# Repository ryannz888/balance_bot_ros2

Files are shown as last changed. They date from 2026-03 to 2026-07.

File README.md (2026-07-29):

# balance_bot_ros2

Two-wheeled self-balancing robot. Raspberry Pi 5 + Arduino Mega + IMU + depth camera, ROS 2 Jazzy.

Stands on its own indefinitely, drives under gamepad or keyboard control while balancing,
stops itself when the depth camera sees something in the way, and will drive around
a room on its own, turning away from whatever it finds.

| | measured |
| --- | --- |
| Continuous balance | **361 s** in one unbroken segment, still upright when recording stopped |
| Driving | **755 s** of gamepad driving with zero falls |
| Pitch error, station keeping | **0.34 deg RMS**, inside ±1.3 deg |
| Braking distance | **0.10 m** from 0.174 m/s |
| Obstacle scan | 1.98 m baseline with 0.01 m scatter; detects at 0.53–0.71 m |
| Autonomous | **486.9 s** of unbroken balance while driving, turning and reversing on its own |

## What was actually hard

A balancing robot is open-loop unstable and **non-minimum phase**: to slow a forward roll the
wheels must first drive *forward*, so the base moves ahead of the centre of mass and the body
pitches back. Get that backwards and the outer loop becomes positive feedback.

That is exactly what happened. `kp_v` was positive for three days and the robot could not hold
more than 8 seconds. The fix came from deriving the sign twice — once from the physical
transient, once from the characteristic equation `s² − K'·kp_v·s − K'·ki_v = 0`, which requires
both gains negative for stability. Setting `kp_v = −0.005` took the longest run from **7.8 s to
367 s in a single step**.

The rest of the tuning was data-driven rather than trial and error:

- **Damping vs stiffness.** A slow 0.45 Hz surge looked like too little damping. Estimating
  ζ ≈ 1.31 from the observed period showed the loop was already overdamped, so the answer was
  more position stiffness, not more damping.
- **The balance point was measured, not guessed.** While balancing with zero mean wheel speed,
  the mean pitch *is* the mechanical balance point: 7.53°. Judged by the velocity integral
  collapsing from −322 to −49 and no longer clamping.
- **Judder was identified as loop self-excitation, not mechanical resonance** — the oscillation
  frequency moved from 9.18 Hz to 7.07 Hz when a software filter coefficient changed, which a
  structural resonance cannot do. Lowering `kd` removed it at no cost to station keeping.
- **A regression was traced to a loose fastener, not to parameters.** Several unrelated metrics
  degraded at once and reverting the parameter did not restore them. That pattern is now a
  documented rule: stop tuning, inspect hardware.

Perception and autonomy produced the same kind of findings. The robot stopped far from
obstacles not because thresholds were timid but because the corridor was a wedge, which
flares to eight times the robot's width at 3 m. It drove into a table leg it had tracked
the whole way in, because the guard's speed taper and the explorer's turn threshold
overlapped into a dead zone where neither reacted, at a commanded speed the drivetrain
cannot even produce. And it engaged while not balanced because a frozen IMU reading
presents as constant error with zero rate -- which is exactly the condition for engaging.

Full reasoning, including the negative results and the conclusions that were later
overturned, is in [`docs/`](docs/).

## Architecture

```text
HFI-A9 IMU ──USB──► hfi_imu_node ──► /imu/data (~145 Hz)
                                         │
                                    level_frame_publisher ──► base_link_level (gravity-aligned)
                                         │
Astra depth ──► openni2 ──► /depth/image ──► obstacle_scan ──► /obstacle/scan (LaserScan, 30 Hz)
                                                                    │
explorer ──/cmd_vel_auto───┐                                        ▼
                           ├─ cmd_mux ─► /cmd_vel_raw ─► avoidance_guard ─► /cmd_vel ─► balance_controller
teleop ──/cmd_vel_manual───┘  (manual wins)   (limits forward only)     │
                                                                /motor_cmd (PWM/100)
                                                                       ▼
                                    serial_bridge ──"M,<pwm>,<pwm>"──► Arduino ──► motors
                                          ▲                               │
                                          └───"E,<left>,<right>" 100 Hz───┘
```

Each boundary in that chain exists for a reason found by breaking it:

- **`/cmd_vel` vs `/motor_cmd`.** Both teleop and the controller once wrote `/cmd_vel` and
  overwrote each other, so driving while balancing was impossible. `/cmd_vel` is now human
  intent in SI units; `/motor_cmd` is the PWM setpoint.
- **`/cmd_vel_raw` vs `/cmd_vel`.** The guard owns `/cmd_vel`; command sources publish
  `/cmd_vel_raw`. The topic name *is* the enforcement — a source that writes `/cmd_vel`
  directly bypasses the guard.
- **`base_link_level`.** The TF tree roots at `base_link`, so everything downstream implicitly
  treats the body as level. It never is. At 1 m, four degrees of tilt is 7 cm of apparent
  height — the whole difference between floor and obstacle.
- **The corridor is a strip, not a wedge.** It was a fixed half-angle, which flares with
  distance: ±0.30 rad spans 1.86 m at 3 m against a 0.22 m track, so distant objects well
  off to the side read as blocking. That, not conservative thresholds, was why the robot
  stopped while still far from anything.

Driving needed **no new control loop**. The velocity and yaw loops already regulate wheel speed
and left/right difference to zero; teleop only moves those setpoints off zero.

## Failing safe

Losing the link on a balancing robot means falling over, not stopping. Every stage fails closed:

| | |
| --- | --- |
| Command timeout | setpoint ramps to zero, robot keeps balancing in place |
| Setpoint slew limit | a step command would demand an instant lean the body cannot produce |
| Input clamp | `teleop_twist_keyboard` defaults to 0.5 m/s, past what this machine can hold |
| Deadman button | releasing stops the robot |
| No attitude → no scan | `obstacle_scan` publishes nothing rather than a scan that reads clear |
| No scan → no forward | the guard reports `STALE` and allows 0% forward |
| Frozen IMU → disengage | 40 bit-identical pitch samples means a dead source, not a still robot |
| Serial device lost | both serial nodes reopen through the by-id path rather than spinning on a dead handle |
| Unknown ≠ clear | invalid depth pixels are absence of evidence, published as `NaN`, never as free space |

That last one is the one that matters most and the one most easily got wrong — see
[`docs/08`](docs/08_MVP2深度相机接入_2026-07-28.md) for how it was got wrong here first.

## Running it

Installed as a systemd unit, the robot comes up on its own: power it on, set it
upright, and it explores. Holding the gamepad's deadman button takes control;
releasing it returns to exploring half a second later.

```bash
sudo systemctl enable --now balance-bot     # boot into autonomy
journalctl -u balance-bot -f                # live
ls -t ~/robot_logs/                         # per-boot logs and bags
```

By hand, in this order:

```bash
ros2 launch balance_bot balance.launch.py     # stands and drives
./run_camera.sh                               # depth driver
ros2 launch balance_bot autonomy.launch.py    # perception, guard, autonomy, gamepad
ros2 launch balance_bot autonomy.launch.py explore:=false   # manual, still guarded
```

Set the robot upright and let go; it engages itself. Analysis of a recorded run:

```bash
scp -r pi:~/ros2_ws/bags/run1_<stamp> results/rosbag/
python tools/analyze_teleop.py results/rosbag/run1_<stamp>
```

## Hardware

| Component | Role |
| --- | ---- |
| Two-wheeled base with encoders | 277.5 counts/rev, 65 mm wheels, 220 mm track |
| Arduino Mega 2560 | TB6612 motor driver, encoder ISR, serial protocol, command watchdog |
| Raspberry Pi 5 (Ubuntu 24.04, ROS 2 Jazzy) | control, perception, logging |
| HFI-A9 IMU | fused quaternion over USB serial, driver written from the protocol |
| Orbbec Astra depth camera | 640×480 depth at 24 Hz, discontinued — see below |

The Astra is discontinued and its official OpenNI2 repository is gone. The current Orbbec SDK
does not recognise it, and Debian's `libopenni2` ships only the PrimeSense driver. Depth works
here by taking the prebuilt `liborbbec.so` out of `orbbec/ros2_astra_camera`, installing it as
`liborbbec.so.0` because Debian's loader only scans for versioned names, and running the camera
node against Orbbec's own `libOpenNI2` — Debian's enumerates the device but segfaults on stream.

## Tooling

Everything under [`tools/`](tools/) exists because something needed measuring:

| | |
| --- | --- |
| `analyze_teleop.py` | scores a run from the bag, using the controller's own recorded state |
| `analyze_run.py` | replays the controller state machine offline, for bags without it |
| `teleop_sequence.py` | scripted command sequences, repeatable across runs |
| `check_level_frame.py` | verifies the gravity frame by rotating measured gravity through it |
| `depth_geometry.py` | checks a depth frame's 3-D geometry for self-consistency |
| `loadtest_camera.sh` | measures whether streaming depth costs the control loops anything |
| `joymap.py` | maps a gamepad's real axis and button indices in one pass |

Braking distance was never measured deliberately — it was computed from bags recorded days
earlier for tuning, because every teleop command is followed by a release.

## Status

- [x] Week 1–4: IMU driver, motor and encoder verification, serial bridge, URDF and TF
- [x] **MVP0** — keyboard teleop with encoder-driven live RViz
- [x] **MVP1** — balance PID (four-stage cascade), driving under balance, gamepad, recording and analysis
- [x] **MVP2** — depth perception, gravity-aligned obstacle scan, avoidance guard, autonomous wandering
- [ ] Odometry (encoders on a pitching body do not measure ground distance directly), then SLAM

Autonomy steers for gaps rather than stopping at obstacles: every bearing is tested for
whether the robot would fit through it, and the widest gap wide enough is steered toward
while still driving. A 0.4 m opening is taken, a 0.2 m one is refused.

Its limit is the sensor, not the logic. With a 58° horizontal field of view the robot
cannot see where it is about to turn until it has turned, so escaping an enclosed space
is search rather than planning. A wider sensor, or remembering what was seen a moment
ago, is the next real improvement.

Known open items are recorded with reproduction steps rather than omitted — the most
significant is that driving forward can lock up below the static-friction threshold, and why
one attempt to fix it made things worse. See [`docs/07`](docs/07_遥控与录制_2026-07-26.md) §11.

## Engineering notes

- Serial devices open via `/dev/serial/by-id/` — `ttyACM*` numbering drifts across boots
- The left/right harness (motors **and** encoders) was cross-wired at assembly; normalised in
  `serial_bridge` and verified wheel by wheel
- `/joint_states` is decimated to 20 Hz; 100 Hz TF saturates a hotspot link
- The camera driver stamps from its own clock by default, which drifted 17 s and silently broke
  attitude pairing — `use_device_time:=false`
- Depth is never streamed off-board: 640×480 float32 at 24 Hz is ~29 MB/s. The robot computes
  and publishes a 64-range scan instead

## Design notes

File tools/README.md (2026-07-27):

# 调参分析工具

2026-07-25 调参过程中使用的离线分析脚本。用法与结论见
`docs/06_PID调参完全复盘_中文.md`。

依赖：`pip install rosbags numpy`

工作流：

```bash
# 1. Pi 上录包（launch 自带，不用手敲话题清单）
ros2 launch balance_bot balance.launch.py record:=true bag_name:=myrun

# 2. 拉回本地
scp -r pi:~/ros2_ws/bags/myrun_<时间戳> results/rosbag/

# 3. 分析
cd tools
python analyze_teleop.py ../results/rosbag/myrun_<时间戳>      # 有 /balance/state 时首选
python analyze_run.py    ../results/rosbag/myrun_<时间戳> 7.53 3.0 12.0 600 5.0
```

**停录制要用 `SIGTERM` 不是 `SIGINT`**：非交互 shell 里的后台任务会继承
"忽略 SIGINT"，`kill -INT` 打不停 recorder，metadata.yaml 就不会写，
包直接读不了。

## analyze_teleop.py

2026-07-26 起的首选工具。直接读 `/balance/state`，不再离线重放状态机。

```
参数：<bag路径>
```

输出：接管分段、每条遥控指令的**设定值跟随情况**（v_ref→vel、turn_ref→turn，
同时给 ticks/s 和 m/s）、无指令时的站桩指标、以及全程位置漂移。
指令块只统计后半段的均值，避开斜坡未到位的部分。

## teleop_sequence.py

发一段脚本化的速度指令序列到 `/cmd_vel`，用于可复现的阶跃测试。

```
参数：[线速度 m/s] [角速度 rad/s]      默认 0.08 / 0.5
```

**不要用 shell 循环套 `ros2 topic pub` 代替它。** 每次 `ros2 topic pub` 都是新进程，
在 DDS 发现匹配上已有订阅者之前就开始发，VOLATILE 语义下这些消息对尚未被发现的
订阅者直接丢弃。第一次遥控测试就栽在这：包里录到了 34 条前进指令，
控制器的回调**一次都没触发**。本脚本全程只用一个 publisher，
并且在 `get_subscription_count() > 0` 之前不发任何消息。

## analyze_run.py

主力工具。离线复现控制器状态机，逐段输出指标。

```
参数：<bag路径> [offset] [engage_below] [max_tilt] [max_wheel_v] [最短报告时长]
```

输出两张表。第一张按段列出：时长、**退出原因**（`TILT` 倾角超限 / `WHEEL` 轮速超限 /
`END` 录制结束时仍在平衡）、误差范围、平均 PWM、饱和率、**带符号**平均轮速、
最大轮速、过零次数、平均差模轮速（偏航偏置）。

第二张是位置环诊断：位置峰峰值与标准差（单位：轮周）、摆动周期、
速度与误差的 RMS。摆动周期用 0.4 秒滑动平均后的轮速过零来数，
直接数原始轮速会数到噪声（会得到 6~9 Hz 的假结果）。

最后是各 PWM 区间的轮子移动率，用于粗看静摩擦。

## true_offset.py

从平衡数据反推真实机械平衡点，替代静态标定。

```
参数：<bag路径> <当前offset> <kp_v> <ki_v> [velocity_filter_alpha]
```

原理：车在平衡且长时间平均轮速为零时，平均 pitch 就是真实平衡点。
同时重建控制器内部的 `velocity_integral` 并报告其均值与限幅占比——
**零点精修到 0.2° 以下时应以积分均值为判据**（应接近 0 且不限幅），
平均 pitch 在这个尺度上已是 run-to-run 噪声。

## breakaway.py

测负载下的静摩擦突破电压，分正反方向。可同时传多个 bag 合并统计。

```
参数：<bag路径> [更多bag路径...]
```

**关键实现**：只统计"指令已稳定"的样本（与 100 ms 前相差 <15 PWM），
排除 PWM 正在爬升的瞬态。不加这个过滤会系统性低估阈值——
最初正是因此误判"静摩擦不是瓶颈"。

## jerk_trace.py

打印轮速极值时刻前后 2 秒的原始逐点轨迹（pitch / err / rate / pwm / vel / turn）。

```
参数：<bag路径> <offset>
```

聚合统计看不见的问题要靠它。stick-slip 极限环就是用它诊断出来的：
持续给 -45 PWM 而轮速恒为 0，车身自己前倾，PWM 追到 116 才挣脱，
随后暴冲到 341 ticks/s 并过冲到 -2.07°。

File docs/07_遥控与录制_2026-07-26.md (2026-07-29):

# 遥控控制与 rosbag 录制（MVP1 后半段）

> 2026-07-26。前置：`docs/06_PID调参完全复盘_中文.md`（平衡环整定，已完成）。
>
> 本篇记录在已经能站稳的平衡车上加遥控的全过程：架构怎么改、
> 为什么遥控不需要新回路、失效保护放在哪、以及一路踩下来的坑。

---

## 1. 起点与阻塞点

07-25 收工时车能连续平衡 228 秒，但整个系统只有一个 `/cmd_vel`，
而且它被两个语义完全不同的东西同时占用：

| 谁 | 用 `/cmd_vel` 表示什么 | 单位 |
| --- | --- | --- |
| MVP0 键盘遥控 | 人的速度意图 | m/s、rad/s |
| balance_controller | 给 serial_bridge 的 PWM 指令 | PWM/100 |

`serial_bridge` 订阅 `/cmd_vel` 直接转 PWM 下发。所以**只要平衡控制器在跑，
键盘遥控和它就会抢同一个话题互相覆盖** —— 这是加遥控前必须先解决的事，
不是风格问题。

---

## 2. 话题分层

```
teleop ──/cmd_vel(SI单位,意图)──► balance_controller ──/motor_cmd(PWM/100)──► serial_bridge
                                          │
                                          └──► /balance/state (诊断)
```

实现上没有硬改 `serial_bridge`，而是给 `bringup.launch.py` 加了一个
launch 参数，默认值保持 `/cmd_vel`：

```python
DeclareLaunchArgument('motor_cmd_topic', default_value='/cmd_vel'),
...
Node(package='balance_bot', executable='serial_bridge',
     remappings=[('/cmd_vel', LaunchConfiguration('motor_cmd_topic'))]),
```

`balance.launch.py` 里传 `/motor_cmd` 覆盖它。这样 **MVP0 的键盘直驱用法
一行都不用改**，裸 bringup 依然是 `/cmd_vel` 直通电机。

> 经验：给已有系统加抽象层时，把新语义放在**默认值之外**，
> 旧用法就不会被打断。

---

## 3. 核心洞察：遥控不需要新回路

这是本次最值得讲的一点。

平衡车的串级结构里，速度环和偏航环本来就在**调节两个物理量**：

- 速度环把平均轮速调节到 **0**
- 偏航环把左右轮速差调节到 **0**

"站着不动"只是"设定值为 0"的一个特例。所以遥控要做的不是新增控制器，
而是**把这两个 0 换成指令值**：

```python
vel_err  = self.wheel_velocity - self.v_ref      # 原来隐含 v_ref = 0
turn_err = self.turn_velocity  - self.turn_ref   # 原来隐含 turn_ref = 0

offset_trim     = kp_v * vel_err + ki_v * self.velocity_integral
sync_correction = wheel_sync_kp * turn_err
```

改动就是两行里各加一个减号项。已经整定好的增益**完全不用重调**，
因为回路的动力学没变，只是工作点移了。

---

## 4. 单位换算（从已有标定量推，不重新测）

| 量 | 来源 | 值 |
| --- | --- | --- |
| 编码器分辨率 | `serial_bridge` 的 `ticks_per_rev` | 277.5 计数/圈 |
| 轮半径 | URDF `cylinder radius` | 0.0325 m |
| 轮距 | URDF 左右轮 joint origin ±0.11 | 0.22 m |

```
周长 = 2π × 0.0325 = 0.2042 m
ticks_per_meter = 277.5 / 0.2042 = 1358.9        → 1 m/s = 1359 ticks/s
```

节点启动时会把这个数打出来自检，实测日志 `1358.9 ticks/m`，与手算一致。

**由此得到一个重要约束**：安全限 `max_wheel_velocity = 600 ticks/s`
换算过来只有 **0.44 m/s**。而 `teleop_twist_keyboard` 默认速度是 0.5 m/s，
直接超限。所以指令**必须在控制器内部钳位**，不能信任输入源。

偏航换算（差速驱动）：

```
v_left = v - ω·L/2 ,  v_right = v + ω·L/2
turn   = v_left - v_right = -ω·L
turn_ref[ticks/s] = -ω · 0.22 · 1358.9 = -299 · ω    → 1 rad/s = 299 ticks/s 差模
```

负号来自 REP-103：`angular.z` 为正是**左转（逆时针）**，左转时右轮更快，
所以差模设定值取负。台架实测 +0.5 rad/s 得到 `turn_ref = -149.5`，
与 `-0.5 × 0.22 × 1358.9 = -149.5` 完全吻合。

---

## 5. 失效保护三件套

平衡车上遥控失效不是"停下来"，是"摔倒"，所以这部分比功能本身重要。

**① 指令超时回零**（`cmd_timeout_s: 0.5`）
断连、teleop 进程崩溃、手柄没电、Wi-Fi 抖动 —— 任何一种都会让
`/cmd_vel` 停发。此时设定值斜坡回零，**车原地继续平衡**，
而不是保持最后的速度冲出去。

> 这条决定了失效保护必须做在**控制器里**，而不是指望输入端。
> 手柄的死人开关是第二道防线，不是第一道。

**② 设定值斜坡限速**（`cmd_accel_ticks_s2`）
阶跃指令要求车身瞬间改变倾角，非最小相位系统做不到。见第 8 节实测。

**③ 幅值钳位**（`max_cmd_linear_mps: 0.25`、`max_cmd_angular_rps: 1.2`）
无论上游发什么，进环的设定值都在物理可承受范围内。

另外**未接管时输出硬零**：实测在车躺在地上、持续发
`{linear.x: 0.2, angular.z: 0.5}` 的情况下，`/motor_cmd` 全零。

---

## 6. `/balance/state` 诊断话题

改造前，离线分析必须**重放控制器状态机**才能还原哪些时段在平衡
（`analyze_run.py` 的做法）。现在控制器直接把自己的内部视角发出来：

```python
STATE_FIELDS = ('pitch','err','rate','trim','offset','vel','vel_raw','turn',
                'v_ref','turn_ref','vel_int','u','sync','engaged')
```

用 `Float32MultiArray`，字段名写进 `layout.dim[0].label`，
**包本身是自解释的**，不依赖源码版本。48 Hz（IMU 帧率 3 分频）。

这一步的收益在第 8 节体现得很直接：后退超调的机理，是靠逐点打印
`v_ref / vel / trim / err / u` 一眼看出来的 —— 靠聚合统计看不见。

---

## 7. rosbag 录制集成

```bash
ros2 launch balance_bot balance.launch.py record:=true bag_name:=teleopT5
```

launch 里用 `ExecuteProcess` + `IfCondition` 挂 recorder，自动附加时间戳、
mcap 格式、固定 6 话题（`/imu/data /wheel/encoders /joint_states
/cmd_vel /motor_cmd /balance/state`）。省掉每次手敲话题清单，
也保证每个包的话题集一致、可比较。

---

## 8. 遥控整定实录

测试用 `tools/teleop_sequence.py`：前进 / 后退 / 左转 / 右转，
各 3 秒，间隔 6 秒（间隔同时在验证指令超时）。

### T1 — 测出来的是测试脚本的 bug

分析报告只有两个偏航指令块，两个直线指令块**完全没有**。
但包里明明录到了 34 条 `linear.x=0.08`。

进一步查：`v_ref` 全程精确为 `0.000000`，控制器日志里"遥控指令接入"
只出现 **2 次**（应该 4 次）。

**根因**：测试脚本用 shell 循环套 `ros2 topic pub`，每条指令一个新进程。
`ros2 topic pub` 在 DDS 发现匹配上已有订阅者**之前**就开始发，
VOLATILE 语义下这些消息对尚未被发现的订阅者直接丢弃。
录包节点被发现了，控制器没有 —— 于是包里有数据，回调一次没触发。

**修复**：改成常驻单 publisher，且在 `get_subscription_count() > 0`
之前不发任何消息（`tools/teleop_sequence.py`）。

> 教训：**"发出去了"和"收到了"是两回事**。rosbag 记录的是录包节点
> 收到的，不等于目标节点收到的。验证链路要看接收端的证据。

### T2 — 台架验证（车躺地上，未接管）

把设定值斜坡改成与接管状态无关后，可以在车不动的情况下验证整条指令链路：

| 指令 | 期望 | 实测 |
| --- | --- | --- |
| 前进 0.08 m/s | +108.7 ticks/s | **+108.7** |
| 后退 0.08 m/s | −108.7 | **−108.7** |
| 偏航 ±0.5 rad/s | ±149.5 | **±149.5** |
| 斜坡 250 ticks/s² | 0.43 s 到位 | ~0.4 s |
| 超时回零 | 0.5 s 后衰减 | ✓ |

`engaged` 全程 0，电机硬零。**能在不冒摔车风险的情况下验证的东西，
就不要在车上验证。**

### T3 — 第一次真正行驶

4 条指令全部生效。但出现两个问题。

**问题 A：跑飞保护误触发 3 次**

```
raw=-639.1  filtered=-306.8
raw=-620.6  filtered= -71.7    ← 滤波后几乎静止
raw=+818.3  filtered= +51.6    ← 滤波后几乎静止
```

原判据用的是**未滤波**轮速。而 277.5 计数/圈、10 ms 窗口下，
**一个计数就是约 100 ticks/s**，raw 信号逐帧在 0 和 ±300 之间跳。
包里 raw 峰值 687、滤波后仅 356。

**修复**：判据改用滤波轮速。时间常数 `dt/alpha = 0.01/0.06 ≈ 0.17 s`，
真跑飞仍能在 0.3 s 内切断，且上面还有 12° 倾角保护兜底。

> 保护判据应该看**持续量**，不是单帧尖峰。这个 bug 在整定阶段就存在，
> 只是原地站桩时轮速小、没暴露出来。

**问题 B：后退超调 190%**（v_ref −98 → vel −283）

**修复尝试**：斜坡 250 → 120 ticks/s²。

### T4 — 斜坡修复只治好了一半

| 指令 | v_ref | 实测 vel | 跟随 |
| --- | --- | --- | --- |
| 前进 | +87.8 | +91.6 | **104%** ✓（T3 是 130%） |
| 后退 | −88.3 | −266.5 | **302%** ✗ |
| 左转 | −139.7 | −120.1 | 86% |
| 右转 | +140.7 | +92.8 | 66% |

保护误触发从 3 次降到 1 次，且整段序列在**单次 120 秒接管**内跑完。
前进被治好了，后退没有 —— 说明后退不是斜坡问题。

**逐点数据揭示：这根本不是"超调"，是稳态。**

```
t=744.9 … 746.6   v_ref=-108.7   vel≈-275   trim≈+1.35   u≈-50..-80（未饱和）
```

`vel` 稳稳停在 −275 长达两秒。验算：

```
vel_err = -275 - (-108.7) = -166
kp_v × vel_err = -0.008 × -166 = +1.33     ← 与实测 trim +1.35 吻合
```

**回路完全在按设计工作**，问题在结构：行驶时我把积分泄放掉了
（为了避免松手倒车找位置），速度环退化成**纯 P**。
纯 P 无法消除稳态扰动，只能用误差换力矩。

后退需要 **+1.43° 的常驻前倾**才能维持那个速度；kp_v = −0.008
要产生 +1.43°，就必须**允许** 179 ticks/s 的误差。
前进需要的 trim ≈ 0，所以前进跟随 104%。
**跟随度的不对称，就是所需 trim 的不对称除以一个太小的增益。**

### T5 — 给速度环补回积分权限

`drive_integral_leak_s: 0.5 → 3.0`。

泄放积分的稳态是 `I = τ · vel_err`，于是等效增益：

```
kp_v + ki_v·τ = -0.008 + (-0.005 × 3) = -0.023      约 3 倍刚度
```

**可证伪预期**：同样需要 +1.43° trim，误差应从 179 降到
`1.43 / 0.023 ≈ 62` ticks/s，后退实测速度应落在 **−150 附近**（而非 −275）；
前进本就不需要 trim，应基本不变。

**结果：这一轮作废，但作废的原因本身很值得记。**

车在序列开始前 3 秒就摔了（接管段 281.1→304.8 s，第一条指令在 308.1 s），
所以四个"指令块"全是零 —— 那是电机已断电后的记录，不是跟随失败。

先说一个**我判断错了又自己纠正**的过程，因为纠正的方法比结论更有用。

摔倒瞬间的数据长这样：

```
304.5   vel -54.3   trim 1.76   err -0.59   pitch  8.71   u  -33.3
304.6   vel -51.2   trim 1.76   err -3.92   pitch  5.36   u -255.0
304.6   vel -52.2   trim 1.76   err -9.36   pitch -0.07   u -255.0
304.7   vel -220.1  trim 3.16   err -12.83  pitch -2.15   u -255.0
```

pitch 在约 0.2 秒内从 8.71° 掉到 −2.15°，而**轮速几乎不动**（−54 → −52）。
我的第一反应是机械失效：车身相对轮轴转了，而轮子没动，只有连接件松脱
才会这样；何况本项目有两次紧固件松动前科。

**但在下结论前先查了采样间隔**：

```
    t          dt      pitch
 304.5298   0.3637      8.71     ← 364 ms 没有数据
 304.5359   0.0061      8.72     ← 之后 11 帧挤在 27 ms 内
 304.5412   0.0053      8.35
 ...
 304.5629   0.0024     -0.07
```

不是机械失效，是 **IMU 管线停摆 0.36 秒后缓冲区一次性倾泻**。
控制器在那 1/3 秒里**没有任何新数据**，一直输出停摆前算出的 `u≈-33`，
车就在瞎着的时候倒了。所谓"0.2 秒塌陷"其实是 **0.36 秒的真实动作
被压缩进 27 ms 回放**。

进一步统计四轮全部 IMU 消息：

| run | 消息数 | 速率 | 中位 dt | p99 | 最大 dt |
| --- | --- | --- | --- | --- | --- |
| T1 | 36632 | 147 Hz | 0.0060 | 0.0081 | 0.010 |
| T3 | 71981 | 145 Hz | 0.0061 | 0.0082 | 0.010 |
| T4 | 121127 | 145 Hz | 0.0061 | 0.0082 | 0.010 |
| T5 | 66644 | 144 Hz | 0.0061 | 0.0082 | **0.344** |

**约 29.6 万条消息里只有这一次间隔超过 10 ms。** 偶发，不是慢性病。

> **方法论**：看到"突变"先问一句**采样是不是连续的**。
> 时间轴上的空洞会把缓慢过程伪装成瞬间事件，进而把软件问题伪装成硬件问题。
> 判据很简单：查 dt。这一步花了两分钟，省下的是拆车的时间。

对控制器本身无需改动：停摆期间控制器不发布，`serial_bridge` 的
0.25 s 看门狗会自动清零 PWM。364 ms 的盲区对平衡车是致命的，
任何控制律都救不回来，真正的解法在 IMU 驱动的健壮性，
但 1/30 万的发生率暂不值得投入。

### T7 — 冷机：温漂假设的判决性实验

隔夜断电冷却后重新开机（开机 3 分钟内采数）：

```
冷机平均 pitch   7.532°        配置 offset 7.53
偏差            +0.002°        ← 前一晚收工时是 -0.49°
velMean         -0.5 ticks/s   （近零，均值才有意义）
velInt mean     +9             （近零，不限幅）
连续平衡        351.2 秒       （零故障，停录制时仍在站）
```

**温漂假设成立**：前一天两小时单调滑掉的 0.86° 完全归零。

一句限定：电池同时被充过。但电压**无法解释这个现象** ——
漂的是 IMU *测出来的* pitch，电压既不移动重心也不改变 IMU 读数，
它只影响电机权限（表现为误差与出力变大，不是平衡点位移）。
故机械方向可以排除。

同口径误差对比也随之闭环：

```
A10 (07-25):  errRMS 0.30~0.31°   range [-0.95,+1.00]   |u| peak <70
T8  (冷机)  :  errRMS 0.34°        range [-1.27,+1.13]   |u| p99  66
```

前一天"errRMS 退化到 0.50"确系跑热后平衡点偏移所致，控制器本身没有变差。

### T8 — 后退修复验证（leak 3.0）

| 指标 | T4 (leak 0.5) | T8 (leak 3.0) |
| --- | --- | --- |
| 连续平衡 | 120.4 s | **361.2 s（全程 100%）** |
| 故障 | 1 | **0** |
| 后退跟随 | −266.5（302%） | −157.6（179%） |
| 前进跟随 | +91.6（104%） | +113.2（128%） |

预测 −150，实测 −157.6，差 5%。机理确认。

**但暴露出一个真正的遥控缺陷**：净位移 **+0.01 rev** ——
车精确地回到了出发点。前进指令结束 5 秒后倒退了 277 mm。

原因不是残留积分（指令结束瞬间 `vel_int` 只有 +19，折合 trim 跳变 0.1°），
而是**指令结束后积分重新累积**：此刻车位移在原点前方 1.11 rev，
位置环的职责就是把这个位移积回零。
遥控要的是"停在你把它开到的地方"，不是"回到原点"。

修法：`reset_integral_on_stop` —— 从行驶切回站桩的那一刻清零位置积分，
等于把当前位置定义为新的保持点。

### T9 — 位置保持点修复：有得有失

净位移 +0.01 → **−2.43 rev**，车不再爬回原点 ✓

但后退跟随从 −157.6 退到 −225.8。

**原因是 T8 那个数被污染了**：前进指令结束后积分累积到 −148，
这份残留在随后的后退指令里恰好提供了额外制动。清零后这份"免费帮助"消失，
**−225.8 才是干净的真实值**。

> 这类"修复导致指标退步"的情况要先问：**退步的那个指标，
> 之前的好成绩是不是靠某种副作用得来的？** 是的话，退步反而说明修对了。

### T10 — 最终配置（leak 6.0 + 位置重置）

既然位置重置已经消除了长泄放时间常数的副作用，两者就是互补的：
**长泄放买行驶期的跟随权限，重置阻止这份权限事后把车拖回旧位置。**

| 指标 | T9 (leak 3.0) | **T10 (leak 6.0)** |
| --- | --- | --- |
| 后退跟随 | −225.8（257%） | **−71.3（81%）** |
| 前进跟随 | +128.9（146%） | **+107.3（122%）** |
| 左转跟随 | — | −127.5 / −140.1（**91%**） |
| **峰值 PWM** | 255（饱和） | **95.3** |
| 误差范围 | [−2.02, +1.50] | **[−1.05, +1.24]** |
| 接管率 | 201/203 s | **276/276 s** |

**跟随变好的同时峰值出力从饱和的 255 掉到 95** —— 这是控制质量真正改善的
标志，而不是拿力气换精度。

预测 −126、实测 −71.3，**量级预测偏了**（方向和数量级对）。
原因：+1.43° 那个"所需常驻倾角"是在差跟随条件下测的，
跟随一好速度就低、扰动也小，线性外推自然偏。

**遗留**：右转跟随仅 28%（左转 91%），偏航方向存在明显不对称，见 T11~T13。

### T11~T12 — 偏航修复 + 零点自适应

**偏航根因不是增益不够，是限幅卡在静摩擦以下。**

```
左转   sync 均值  +8.2                    ← 车本身偏左，只需一点点
右转   sync 均值 -34.3   峰值 -59.2       ← 1% 采样顶到 60 上限
                                            而实测负载突破 PWM 是 65~80
```

`0.4 × 误差 = sync` 两方向都精确吻合，**P 律一直在正确执行**，
但右转所需修正量整个生命周期都在突破阈值以下，轮子挣不脱。

修法：`max_wheel_sync_pwm` 60 → 110（越过突破电压），
外加泄放积分 `wheel_sync_ki=0.08` / `turn_integral_leak_s=6.0`
（等效低频增益 0.4 + 0.08×6 = 0.88）。用泄放而非纯积分，
是为了误差消失后自行衰减、不锁死航向。

结果：**右转 28% → 91%，左转 91% → 99%。**

并且确认**没有串扰**：直线指令期间 sync 峰值仅 18（老配置是 24），
比修改前还安静 —— 提高偏航权限没有污染直线通道。

**零点自适应**（`offset_adapt_tau_s=120`）：站桩且平均轮速为零时，
速度环平均要顶住的 trim 就等于零点误差，慢慢把它吸收进 `offset_bias`。

同口径对比：

| | T10 | T12 |
| --- | --- | --- |
| 站桩 errRMS | 0.59° | **0.38°**（历史最好） |
| 站桩 trimMean | +0.356 | **+0.046** |

`trimMean` 逼近零就是自适应生效的直接证据。

> **两个统计陷阱，都是被用户当场纠正的：**
>
> 1. 我用 `grep -c '已接管'` 数出"17 次摔倒"，用户说只摔了两次。
>    `latch_on_fall: false` 下，扶车过程中车会反复穿过接管窗口，
>    **一次物理摔倒能刷出好几行日志**。正确做法是数
>    *持续时间足够长的接管段之间的中断*（已加进 `analyze_teleop.py`）。
>    我基于错误计数说过"这个特性有害"，那个判断作废。
> 2. 我报告 T12 站桩 errRMS 0.88 是"退步"，实际是被一段 45 秒的
>    摔倒数据污染了；剔除后是 0.38，反而是历史最好。
>    **分段统计前先确认每段的状态是同质的。**

### T13 — 行驶抖动

用户反馈"前进后退时存在抖动"。频谱直接定位：

| | 主频 | u 峰峰值 |
| --- | --- | --- |
| 前进 | **9.18 Hz** | **397 PWM** |
| 后退 | **9.18 Hz** | 394 PWM |
| 站桩 | 0.32 Hz（慢摆） | 156 PWM |

行驶时输出几乎在 ±200 PWM 之间来回甩。站桩看不出来，是因为
车身动作小、激励不足；一行驶，静摩擦反复挣脱就是宽带激励，
把回路在自激点上"敲响"。

D 项嫌疑：`pitch_rate_filter_alpha=0.3` 在 145 Hz 下截止约 6.9 Hz，
振荡在 9.2 Hz —— 正好在截止之上，滤波器已开始产生相位滞后。
估算 9.2 Hz、±0.3° 振荡对应角速度 17 °/s，乘 `kd=5` 就是 86 PWM，
D 项在该频率上是主导项。

改 `pitch_rate_filter_alpha: 0.3 → 0.15`（截止降到 3.5 Hz）：

```
前进 err 主频  9.18 Hz → 0.46 Hz    车身抖动消失
后退 err 主频  9.18 Hz → 7.07 Hz    err RMS 0.63 → 0.45
```

> **关键诊断：振荡频率跟着滤波系数一起移动了（9.18 → 7.07 Hz）。**
> 这一条排除了机械谐振 —— 结构谐振的频率由结构决定，
> 不可能因为改一个软件系数就变。所以是**控制回路自激**，
> 自激点由 D 通道的相位滞后决定。
>
> 推论：改滤波只能把自激点挪低，要消除必须降低该频率上的环路增益
> （降 `kd`），或者从根上换掉信号源 —— 用陀螺原始
> `angular_velocity.y` 代替 pitch 差分，就没有微分噪声，
> 也就不需要这么重的滤波，相位裕度直接改善。**后者是真正的解法。**

---

## 9. 踩过的坑（工程环境类）

这几个都跟控制无关，但都真实浪费了时间，值得记。

**① `pkill -f` 会匹配到自己**

```bash
ssh pi "pkill -f balance_controller"     # 命令行里含 "balance_controller"
```
pkill 匹配全命令行，**把自己所在的 ssh shell 也杀了**，后续命令不执行。
结果两套 stack 同时在跑、两个 `serial_bridge` 同时写 Arduino 串口，
IMU 报 "multiple access on port"。

改用括号写法：`pkill -f '[b]alance_controller'` —— 正则匹配
`balance_controller`，但字面量 `[b]alance...` 匹配不到自己。

**② 非交互 shell 的后台任务忽略 SIGINT**

POSIX 行为：非交互 shell 里以 `&` 启动的后台任务会继承 `SIGINT = SIG_IGN`。
所以 `kill -INT` 停不掉 rosbag recorder，**metadata.yaml 不写，
整个包读不了**。必须用 `SIGTERM`。

**③ ssh 后台进程会挂住 ssh 会话**

`nohup ... &` 不够，ssh 会等 channel 关闭。要 `setsid nohup ... < /dev/null > log 2>&1 &`，
且 stdin 重定向不能省。

---

## 10. 手柄接入（预置，硬件未到）

`/cmd_vel` 是 SI 单位的意图话题，**输入设备与控制器完全解耦**：

```
键盘 / USB手柄 / 2.4G手柄 / 手机  ──► /cmd_vel ──► balance_controller
                 ↑ 随便换，控制器一行不改
```

已备好 `launch/teleop_joy.launch.py` + `config/teleop_joy.yaml`：

```bash
sudo apt install ros-jazzy-joy ros-jazzy-teleop-twist-joy
ros2 launch balance_bot teleop_joy.launch.py
```

用 `game_controller_node` 而不是 `joy_node`：前者走 SDL GameController API，
把各品牌手柄的按键布局**归一化**成同一套语义，换手柄不用重推按键序号。

关键配置：`require_enable_button: true` + `enable_button: 9`（LB 死人开关）。
松手 → `/cmd_vel` 停发 → 控制器 `cmd_timeout_s` 超时 → 设定值归零 →
**车原地继续平衡**。

### 2026-07-28 实机接入结果

买的 2.4G 手柄（USB 接收器）在内核里枚举为 `045e:028e Xbox360 Controller`，
走 XInput，`xpad` 驱动直接认，`/dev/input/js0` 开箱即用，**零驱动配置**。
`game_controller_node` 报 `X360 Controller`，SDL 标准布局适用。

实测映射（用 `tools/joymap.py`，一次会话把整个手柄测完）：

| 项 | 原配置 | 实测 | 结论 |
| --- | --- | --- | --- |
| `axis_linear.x` | 1，scale **−0.12** | 左摇杆前推 = **+1.0** | 索引对，**符号错** |
| `axis_angular.yaw` | 2，scale +0.8 | 右摇杆左推 = +1.0 | ✓ |
| `enable_button` | 9 | LB = 9 | ✓ |
| `enable_turbo_button` | 10 | RB = 10 | ✓ |

**符号那条是真 bug**：我当初按 SDL 原始约定（上推为负）把 scale 写成负数，
但 `game_controller_node` **已经替你取过反了**。照原配置推前进会变成后退。
改成 +0.12 后实测 `/cmd_vel` 输出 `x: +0.12`、`z: +0.80`，两个方向都对。

> 这条值得记的是**验证方式**：整条链路在车没启动的情况下验完的 ——
> 只起 teleop，不起平衡控制器，看 `/cmd_vel` 的符号。
> 电机全程零输出，符号错了也没有任何代价。

`joymap.py` 的存在本身也是个教训：隔着 SSH 用 `ros2 topic echo` 一次试一个键，
按键总落在 echo 窗口外，试了三轮一无所获；改成常驻订阅、
**首次变化即打印**，一次就把整个手柄测完了。

**装包时踩的坑**（与手柄无关，但会挡住任何人复现）：
`apt install ros-jazzy-joy` 报依赖冲突，`libdbus-1-dev` 等三个包要求旧版运行时库。
根因是 `/etc/apt/sources.list.d/ubuntu.sources` 里**只有 `noble` 和 `noble-security`，
缺 `noble-updates`** —— 安全更新把运行时库升了级，而配套 `-dev` 包的更新在
`noble-updates` 里，没启用就永远取不到匹配版本。补上该源即解决。
这是系统源配置缺失，以后装任何带编译依赖的包都会撞上。

**选型结论**：Pi 5 的 Wi-Fi 和蓝牙共用一颗芯片同一路 2.4GHz 射频（CYW43455），
而本项目全靠 Wi-Fi 热点跑 DDS。因此优先选 **2.4G USB 接收器**款
（独立射频，不与 Wi-Fi 争资源），而不是蓝牙手柄。
PS2 手柄不走 USB 协议，接 Pi 需要自己写 GPIO 位操作驱动
（且 Pi 5 换了 RP1 南桥，`RPi.GPIO` / `pigpio` 全部失效），不值得。

---

## 11. 遗留问题

**① IMU 零偏随通电时间漂移（已确认，未处理）**

| run | 时间 | 平衡段平均 pitch | 相对 offset 7.53 |
| --- | --- | --- | --- |
| T1 | 07-26 15:47 | 7.895° | +0.37° |
| T3 | 07-26 16:15 | 7.706° | +0.18° |
| T4 | 07-26 16:59 | 7.287° | −0.24° |
| T5 | 07-26 17:22 | 7.039° | **−0.49°** |
| **T7** | **07-27 10:27（冷机）** | **7.532°** | **+0.002°** |

连续会话内单调漂移 0.86°，**断电冷却一夜后完全归零**。
关键特征是单调 —— 既排除随机噪声，也不像紧固件松动（松动是突变）。

影响：跑热后 offset 偏了，站桩 errRMS 从 0.31° 劣化到 0.50°，
且行驶时的方向不对称被放大。

处理思路（按代价排序）：
(a) `capture_offset_on_engage` —— 每次接管时重新捕获平衡点，
    机制已存在且已实现（`capture_settle_time_sec` / `capture_rate_below_dps`），
    目前关闭。代价最低，但每次接管的捕获值本身有噪声；
(b) 让速度环积分在长时间尺度上吸收零偏（等价于在线估计），
    需要把站桩积分的时间常数拉得很长且做好抗饱和；
(c) 读 IMU 温度输出做补偿，最彻底但要先确认 HFI-A9 是否输出温度。

**② ~~IMU 管线~~ 系统级偶发停摆**

实测 29.6 万条消息中出现一次 344 ms 空洞，足以让平衡车摔倒
（详见第 8 节 T5）。发生率约 1/30 万，暂不处理，但需知道
**它存在，且症状会伪装成机械失效**。

> **⚠️ 2026-07-28 更正：这不是 IMU 的问题，标题里的归因是错的。**
>
> 后来同时录 `/imu/data` 和 `/wheel/encoders` 做对照，发现同样的 ~340 ms 空洞
> **在两路上同时出现**（起点相差仅 0.093 s）。这两个是完全独立的 USB 串口设备
> （IMU 走 CP2102，编码器走 Arduino），不可能同时故障 ——
> **是系统级停摆，IMU 只是被连累的**。
>
> 当时只盯着 `/imu/data` 一路的时间戳，**没有对照另一路独立数据源**，
> 于是把"共因"误读成了"IMU 的病"。排查方向应转向调度器/内核
> （`journalctl -k`、CPU 节流、WiFi 中断延迟）。
> 详见 `docs/08_MVP2深度相机接入_2026-07-28.md` 第 4 节。

**③ 行驶抖动：7 Hz 回路自激（部分缓解，未消除）**

已确认是控制回路自激而非机械谐振（依据见 T13：频率随滤波系数移动）。
`pitch_rate_filter_alpha` 降到 0.15 后前进抖动消失、后退降到 7.07 Hz。

> **⚠️ 更正：06 篇遗留项里"用陀螺原始 `angular_velocity.y` 替代 pitch 差分"
> 这条建议，在本机上是错的，已被实测推翻。不要照做。**

轴向标定可以**直接从已录的包离线做**，`/imu/data` 本来就带 `angular_velocity`，
不需要碰硬件。把三轴分别与 pitch 差分做相关（T12 包，13.6 万样本）：

```
angular_velocity.x :  r = -0.063     无关
angular_velocity.y :  r = +0.835     就是它，符号为正，不需取反
angular_velocity.z :  r = +0.031     无关
```

轴向和符号都确认了。但**换过去会让抖动更严重**，因为陀螺那一路是滞后的：

```
谱分析   6~9 Hz 幅值比 1.02，相位 d(pitch)/dt 超前陀螺 +50.6 度
互相关   峰值在 -3 采样 = -18.1 ms（r 由零延迟 0.813 升到 0.946）
交叉验证 18 ms 在 7.7 Hz 处 = 0.018 x 7.7 x 360 = 50 度，与谱分析吻合
```

**四元数推出的 pitch 角速度比陀螺读数早 18 ms**，推测是 HFI-A9 片上融合对
四元数做了预测，而角速度那一路多过了一层低通。换成陀螺等于在自激点上
再叠 50 度相位滞后，只会更糟。

（顺带纠正一个统计细节：最初用 `polyfit(gyro, dpitch)` 得到斜率 0.82，
看着像幅值衰减。那是**自变量带噪声导致的回归衰减偏差**；
谱比给出的 1.02 才是无偏结果。**自变量有噪声时不要用回归斜率估增益。**）

**所以剩下的路是降低自激频率处的环路增益** —— 降 `kd`。**已验证，有效。**

同一次会话内背靠背对比（第 1 轮 kd=5.0，第 2、3 轮在线改成 3.5，
不重启不重扶，地面位置和温度都相同）：

| 序列 | kd | 前进 err 主频 | 前进 u 峰峰值 |
| --- | --- | --- | --- |
| 1 | **5.0** | **7.00 Hz** | **356.5** |
| 2 | 3.5 | 0.45 Hz | 146.7 |
| 3 | 3.5 | 0.44 Hz | **127.4** |

kd=3.5 的所有指令段里 `err` 主频都回到 0.44~0.45 Hz（本来就有的慢摆），
**7 Hz 分量从车身运动里彻底消失**，输出峰峰值降到三分之一。

代价检查（降 kd 等于减阻尼，必须确认平衡质量没被牺牲）：

| 窗口 | kd | 站桩 errRMS | 误差范围 | \|u\| p99 |
| --- | --- | --- | --- | --- |
| 120-150s | 5.0 | 0.35 | [−1.19, +1.21] | 65 |
| 280-315s | 3.5 | 0.38 | [−1.11, +1.51] | 79 |
| 360-400s | 3.5 | **0.34** | [−1.05, +1.43] | 71 |

**0.34~0.38 对 0.35，在 run-to-run 噪声以内。** 让出去的那部分阻尼，
本来就只是在喂养振荡。

> 中间有个窗口（200-235s）测出 errRMS 0.81、误差范围 [−11.88, +2.91]，
> 看着像 kd=3.5 严重变差。查了一下，那段**跨了一次摔倒**（接管段在 205.8s 断开）。
> 又一次同样的陷阱：**分段统计前先确认每段状态同质**。

**结论**：抖动问题收敛。若将来还需进一步压制，再考虑 D 通道加 7 Hz 陷波器。

**④ 直线跟随率不可重复 —— 大概率是测量方法的问题，不是控制问题**

> **2026-07-27 更新：下面"环境扰动/地面坡度"的推断已被 180 度实验推翻。
> 当前判断是测量窗口太短。**

**180 度判决实验**（同一位置，只把车原地转 180 度，各跑一轮）：

```
              bias(站桩)          trimMean   平均时长
A 原朝向      +0.390 -> +0.413    +0.035     184 s
B 转 180 度   +0.384 -> +0.418    +0.032     203 s
```

零点自适应开着时，坡度所要求的常驻倾角会被吸收进 `offset_bias`，
所以 **`bias` 才是坡度指示器**（`trimMean` 被自适应按设计压到零，不能用）。
两个朝向的 bias **相差 0.005 度** —— 有坡的话应该相差两倍坡度角。
**地面坡度排除。**

原先基于指令段 trim 做的"共模/差模"分解**不可信**：它假设指令段达到了稳态，
而实际没有 —— B 轮后退指令下车竟然朝前走了 +34.5（设定值 −88），方向都反了，
那个 trim 数值不代表任何"所需常驻倾角"。

**真正的嫌疑：测量窗口短于被测信号的周期。**

车有一个 **0.45 Hz 的慢摆模态**（周期 2.2 s，每一轮数据里都稳定出现）。
而指令只有 3 s，取"后半段"平均就是 **1.5 s，不到一个完整摆动周期**。
在一个正在摆动的量上取不足一周期的平均，结果完全取决于恰好落在哪个相位。

佐证：跟随率在 8 轮 20 条指令里从 4% 跳到 302%（75 倍），
而**同一批数据里所有其它指标都高度可重复** ——
站桩 errRMS 0.34~0.38、bias、偏航跟随 91%/99% ——
**唯独这一个指标不稳定，也唯独它的测量窗口短于被测信号周期。**

指令起始时刻的速度只解释了一小部分（r ≈ −0.43，n=10，不显著）。

**已执行**：指令时长 3 s → 12 s（`HOLD_S`），并按 2.2 s 子窗口拆开看。
结果部分推翻了"测量假象"的判断，而且挖出了真正的原因。

```
12 s 指令，各 2.2 s 子窗口的跟随率：
  前进   127  65   0   0   0     <- 走约 4 秒后彻底停死
  后退   128 132 137 162 145     <- 高度一致
  左转    89  71  70  43
  右转    64  94  64  51
```

后退的一致性证明**加长窗口确实让测量稳定了**（原来 3 s 窗口下同一条指令
在各轮之间从 179% 跳到 302%）。但前进不是相位散布，是**真的停住**。

### ④ 真正的原因：低误差死锁（stall lock）

前进指令下停住时的逐点状态：

```
t=155~160s   v_ref +108.7   vel 0.0   vel_raw 0.0（100% 采样为零）
             trim +0.84     err +0.15  pitch 8.96   u ~ 14
```

机理：

1. 速度环发现没到设定速度，把目标倾角抬高到 `trim +0.84`
2. **车身照做了** —— 前倾到 pitch 8.96 正好对上新目标
3. 于是角度环误差只剩 `err = 0.15 度`，它认为一切正常，
   输出塌缩到 **u ~ 14 PWM**
4. 而实测负载静摩擦突破电压是 **65~80 PWM** —— 14 推不动轮子
5. 车前倾着站在原地不动，**形成稳定的死锁平衡**

关键在于回路**没有能力自己escalate**：`drive_integral_leak_s = 6.0`
让位置积分在行驶时持续泄放（实测 `vel_int` 从 28 衰减到 4），
trim 停在 +0.84 再也涨不上去，永远够不到突破电压。

**这解释了跟随率 4%~302% 的巨大方差**：不是相位噪声，
是"这一轮卡住了没有"的二元结果。后退不卡，前进卡。

也和 06 篇的静摩擦结论对上了：那里实测出负载突破 65~80 PWM，
并把静摩擦前馈列为"暂缓"，理由是共模前馈会先松开一个轮子而表现为偏航。

**候选解法**：

(a) **失速时冻结泄放** —— 判据 `|v_ref| > deadzone 且 |vel| ~ 0`，
    让积分正常累积把 trim 顶上去，直到轮子挣脱。
    **已实现并实测 —— 失败，已禁用（`stall_velocity_ticks: 0`）。见下。**
(b) 静摩擦前馈，**必须在左右分流之后逐轮施加**（06 篇的结论）。
(c) 低速抖动（dither），代码里已有 `deadband_dither_hz` 骨架，目前关闭。

### (a) 的失败：用错了执行机构

它**确实挣脱了死锁**，但把系统推进一个发散的极限环：

```
t=295.9  指令未到    vel_int 已 -254   trim +1.68   <- 站桩时就攒了这么多
t=297.1  指令开始    vel_int -281                    （判定失速，继续累积）
t=298.3  挣脱        vel +342.9                      <- 设定值 108.7，冲到 3.2 倍
t=305.1  反冲        vel  -43.2   trim +1.67
t=307.5  更猛        vel -202.8   trim +2.88
```

卡住 → 积分猛涨 → 挣脱 → 暴冲 3 倍 → 过冲修正 → 又卡住 → 循环，
日志里滤波轮速逐轮从 −606 爬到 −1300，是发散不是收敛。

**根本错误在于执行机构选错了，不是数值没调好。**
积分是**秒级的慢状态**；用它去顶穿**毫秒级**的静摩擦突破，
等轮子一动，积分还挂在 −290 上、泄放时间常数 6 秒收不回来，
车就继续加速冲过头。时间尺度根本不匹配。

**正确的方向是作用在输出上**：检测到"要动而没动"时直接在 PWM 上加一个
刚好够突破的量，轮子一动立刻撤掉，**不留任何残留状态**。
也就是方案 (b)。

> 这条负结果值得留着：它给出了一个可复用的判据 ——
> **补偿一个快过程，就得用快执行机构。**
> 慢积分器能改变工作点，但不能用来穿越阈值。

**注意**：`reset_integral_on_stop` 只在指令**结束**时清零，
救不了指令**进行中**的失控，所以它对 (a) 的发散没有帮助。

---

**（以下为已被推翻的原推断，保留以记录推理过程）**

**~~直线跟随的方向不对称：环境扰动，非控制器缺陷~~**

各轮**参数完全相同**，但后退所需的常驻 trim 差 3.4 倍，
而跟随率精确地跟着它走：

| run | 后退实测 | 跟随 | 所需 trim |
| --- | --- | --- | --- |
| T4 | −266.5 | 302% | +1.43° |
| T9 | −225.8 | 257% | +1.23° |
| T12 | −228.2 | 259% | +1.22° |
| T8 | −157.6 | 179% | +0.82° |
| T10 | −71.3 | **81%** | **+0.42°** |

**T10 是异常值，不是常态。** 同一天同一房间、同一套参数下所需 trim
能差 3 倍，说明它不是机器的固有属性，而是**环境扰动**——
最可能是地面坡度（每次扶车放下的位置和朝向都不同）。

**判决实验（未做）**：同一位置跑一次序列，然后把车**原地转 180°** 再跑一次。
trim 需求跟着翻号 → 地面坡度；不翻号 → 车本身（重心偏置或摩擦不对称）。
五分钟可定案，需人配合转车。

**⑤ 沿用 06 篇的遗留项**

每轮独立的静摩擦补偿、电池电压监控。

## 12. 文件索引

| 文件 | 作用 |
| --- | --- |
| `balance_bot/balance_controller.py` | 控制器，含遥控设定值注入与 `/balance/state` |
| `config/balance_params.yaml` | 全部参数，含推导注释 |
| `config/teleop_joy.yaml` | 手柄映射与死人开关 |
| `launch/balance.launch.py` | 平衡 + 录制，`record:=true` |
| `launch/bringup.launch.py` | 硬件，`motor_cmd_topic` 可覆盖 |
| `launch/teleop_joy.launch.py` | 手柄遥控 |
| `tools/teleop_sequence.py` | 可复现的脚本化指令序列 |
| `tools/analyze_teleop.py` | 基于 `/balance/state` 的分析 |
| `tools/README.md` | 工具用法与实现陷阱 |

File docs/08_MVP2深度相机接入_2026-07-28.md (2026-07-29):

# MVP2 第一阶段：深度相机接入与风险验证

> 2026-07-28。前置：`docs/07_遥控与录制_2026-07-26.md`（MVP1 完成）。
>
> 本篇是 MVP2 的**风险验证阶段**：把四个可能推翻计划的未知数逐个证伪。
> 避障逻辑一行没写 —— 这是有意的，见下。

---

## 1. 为什么先做这两件事

MVP2 的常见做法是一上来写避障逻辑。这里反过来，按**风险从高到低**排：

| 序 | 风险 | 为什么排在前面 |
| --- | --- | --- |
| ① | Astra 驱动能不能跑 | 停产硬件，跑不起来整个方案要改 |
| ② | 相机流会不会拖垮平衡回路 | **可能反伤已经做好的 MVP1** |
| ③ | 制动距离多长 | 是后面所有避障策略的输入参数 |
| ④ | 车身摆动下的点云补偿 | 有难度但方案明确 |
| ⑤ | 避障逻辑与状态机 | 前四项都定了才有意义 |

前两项都是**证伪性质**的：花的时间不多，但任何一项失败都会推翻后面的计划。
先做它们，避免在错误方向上投入。

本篇把 ①~④ 全部做完，⑤ 留给下一阶段。

---

## 2. 风险 ①：驱动（已解除）

硬件是 **Orbbec Astra Pro**，2016 年前后的产品，早已停产。

### 设备结构：两半是分开的

```
lsusb:
  2bc5:0501  Astra Pro HD Camera   bInterfaceClass 14 (Video)   Driver=uvcvideo
  2bc5:0403  ASTRA Pro             bInterfaceClass 255 (Vendor) Driver=[none]
```

- **RGB**（`0501`）是标准 UVC，内核直接认，`/dev/video0` 开箱即用
- **深度**（`0403`）是厂商私有接口，**没有内核驱动**，必须由用户态经 libusb 操作

`Driver=[none]` 是正常的，不是故障 —— libusb 类驱动不绑定内核驱动。
但它意味着需要 udev 规则才能让非 root 打开设备：

```
SUBSYSTEM=="usb", ATTR{idVendor}=="2bc5", MODE:="0666", GROUP:="video"
```

### 两次失败，缩小了范围

**尝试 1：`ros-jazzy-orbbec-camera`（官方新 SDK）** —— 失败。

```
Name: Bootloader device,  PID: 0x0501,  SN: (空)
```

它只看到 RGB 那半，还认错成 "Bootloader device"（PID 不在型号表里的兜底标签），
**深度传感器 `0403` 根本没被枚举**。新 SDK 面向 Femto/Gemini/Astra 2，
不含 Astra Pro。

**尝试 2：`ros-jazzy-openni2-camera` + Debian 的 libopenni2** —— 失败。

```
NiViewer2:  DeviceOpen using default: no devices found
list_devices: Found 0 devices
```

Debian 的 `libopenni2` 只带 `libPS1080.so`（PrimeSense）和 `libOniFile.so`（回放）。
Astra 虽是同源芯片组，USB 协议层不同，**必须要 Orbbec 自己的 `liborbbec.so`**。

### 找回驱动

官方 `orbbec/OpenNI2` 仓库已 **404**（停产后删除）。但
**`orbbec/ros2_astra_camera` 还在**，里面带着预编译的 redist：

```
astra_camera/openni2_redist/arm64/OpenNI2/Drivers/liborbbec.so
astra_camera/openni2_redist/arm64/libOpenNI2.so
```

只用 `curl` 取这几个文件，不克隆整个仓库（树莓派走手机热点，省流量）。
下来的是真货：`ELF 64-bit LSB shared object, ARM aarch64`，1.5 MB。

### 两个卡了我一轮的细节

**① Debian 的 libOpenNI2 只认 `lib*.so.0`**

直接把 `liborbbec.so` 拷进系统驱动目录会报：

```
Found no files matching '/usr/lib/aarch64-linux-gnu/OpenNI2/Drivers/lib*.so.0'
```

Debian 打包时改了搜索模式（系统自带那四个驱动全是 `.so.0` 实体 + `.so` 软链）。
文件必须叫 `liborbbec.so.0`。

**② Debian 的 libOpenNI2 与 Orbbec 驱动 ABI 不完全兼容**

放好文件后**枚举成功了**：

```
Device "2bc5/0403@4/8" found.
Uri: 2bc5/0403@4/8 (Vendor: Orbbec, Name: Astra, Product ID: 403)
Serial number: 17122520231
```

对照极干净：**系统 OpenNI2 = 0 个设备，加上 liborbbec.so = 1 个设备。**

但**开流时段错误**。线索在更早的输出里：用 Orbbec 自带的 `libOpenNI2.so` 时
`list_devices` 完整打印了序列号；用 Debian 那版时输出在序列号**之前**就断了。
说明能枚举、深入操作就崩 —— Orbbec 是配着自己那版库测试的。

**解法**：不替换系统库（别的包链接着它），把 Orbbec 的 OpenNI2 整套放在
独立目录，只为相机节点设 `LD_LIBRARY_PATH`（见 `run_camera.sh`）。

### 结果

```
/depth/image      640x480  23.9 Hz  encoding 32FC1 (float32 米)
/depth_raw/image  /ir/image_raw  /projector/camera_info  ...
```

> **教训**：验证要**分层**。先用 `NiViewer2` / `list_devices` 这类
> 不带 ROS 的工具确认"驱动能不能看到设备"，再上 ROS 节点。
> 否则失败时分不清是驱动、ABI 还是 ROS 封装的问题。
> 本次三层各失败一次，正是靠分层才逐个定位。

---

## 3. 风险 ②：相机是否拖垮平衡回路（已解除）

### 第一次测量是错的

用 `ros2 topic hz` 直接量，得到自相矛盾的结果：

```
相机开：IMU 151.5 Hz，编码器  54.4 Hz
相机关：IMU 112.5 Hz，编码器 131.8 Hz
```

IMU 在相机开着时反而更高。两个问题：

1. **`ros2 topic hz` 自己是个 Python 节点**，订阅开销和调度会污染被测量本身
2. **image_transport 是惰性发布的** —— 没人订阅时驱动只占 2.2% CPU、
   根本不产生帧。"相机开着"和"相机在传数据"是两回事，我测的是前者。

### 正确的做法

录包后**离线统计消息间隔**（测量本身零成本），并且**挂真实订阅者**逼相机出流。
见 `tools/loadtest_camera.sh`。B 段实测 CPU 从 2.2% 升到 15.8%，确认在干活。

### 结果

| | 相机关 | 相机开（23.3 Hz 出流） |
| --- | --- | --- |
| IMU 速率 | 144.0 Hz | **144.0 Hz** |
| IMU 抖动 (std dt) | 0.0043 | **0.0012** |
| 编码器速率 | 99.7 Hz | **99.7 Hz** |
| 编码器抖动 | 0.0053 | **0.0021** |

**吞吐量完全不变，抖动反而更小。** 相机流对控制回路没有可测量的负面影响。
Pi 5 四核，`hfi_imu_node` 32%、`balance_controller` 25%、相机 16%，余量充足。

---

## 4. 顺带更正一条 07-27 的归因

`max dt` 那一列暴露了别的东西：

```
相机关：IMU max 0.3369 s   编码器 max 0.3301 s
相机开：IMU max 0.0115 s   编码器 max 0.0169 s
```

相机**关着**的 45 秒里出现一次 **340 ms 停摆**，而且
**IMU 和编码器同时卡住**（两个空洞起点相差仅 0.093 s）。

这两个是完全独立的 USB 串口设备（IMU 走 CP2102，编码器走 Arduino），
不可能同时故障。**这是系统级停摆，不是传感器问题。**

> **更正**：07-27 我把一次 344 ms 的空洞记为"IMU 管线偶发停摆"
> （见 `docs/07` 第 11 节 ②），并据此推断问题在 IMU 驱动。
> **该归因作废。** IMU 是被连累的，真正的原因在调度器/内核层面。
> 当时只录了 `/imu/data` 的时间戳去看，没有对照另一路独立数据源 ——
> **单一数据源看不出"共因"**。

与相机无关（相机开着的时段一次都没出现）。发生率仍然很低，
但既然它能掀翻车（07-27 那次就是），值得单独查。
下一步排查方向：`journalctl -k` 看有无内核事件、
CPU 频率/温度节流、以及 WiFi 驱动的中断延迟。

---

## 5. 风险 ③：制动距离（已测，结果有利）

不需要新实验 —— 前几天遥控数据里每条指令后面都跟着松手，正好是制动过程。
从 `v_ref` 归零那一刻积分轮速直到停住：

| run | 松手时速度 | 停止耗时 | 滑行距离 |
| --- | --- | --- | --- |
| T10 | 0.078 m/s | 0.73 s | 0.035 m |
| slopeA | 0.103 m/s | 0.87 s | 0.049 m |
| T12 | 0.131 m/s | 0.83 s | 0.081 m |
| joydrive | 0.174 m/s | 0.93 s | **0.102 m** |

**最坏 10 cm，停止耗时稳定在 0.9 s。** 距离随速度近似线性，
外推到限速上限 0.25 m/s 约 0.15 m。

**这解除了对 Astra 盲区的担心**：最近感知距离 0.6 m 是最坏制动距离的 **6 倍**。
加上检测延迟（相机 24 Hz = 42 ms，含处理约 100~200 ms，折合 3.5 cm），
总制动距离仍在 0.15 m 量级。按线性外推要让制动距离逼近 0.6 m 需开到约 1.0 m/s，
远超本机物理上限（安全限对应 0.44 m/s）。

> **限定**：这是**正常指令停车**。地面打滑、或撞上前进静摩擦死锁
> （见 `docs/07` 第 11 节 ④），行为不同。避障策略要留安全系数。

---

## 6. 风险 ④：重力参考系（已实现并验证）

### 问题

TF 树根在 `base_link`，**上面没有任何重力参考**：

```
base_link  ← 根
├── left_wheel / right_wheel   (动态)
├── camera_link → camera_optical_frame  (静态)
└── imu_link                    (静态)
```

所有消费者都隐含假设车身水平。而这是平衡车 —— 站桩时在平衡点两侧摆约 1°，
行驶时外环把它倾到 4°。深度数据因此落在一个**摇晃的坐标系**里，
**平地看起来是斜的**：1 米处 4° 对应 7 cm 的高度误差，
这正好是"地面"和"障碍物"的分界。

### 实现

`balance_bot/level_frame_publisher.py` 发布 `base_link -> base_link_level`，
同原点、**去掉俯仰与横滚、保留航向**（X 仍指向车头方向）。
把深度点变换到 `base_link_level`，高度就是相对重力量出来的。

**刻意没有发布成 `odom -> base_link`**：odom 按约定是世界固定的里程计坐标系，
而这个节点没有位置估计。平移恒为零却叫它 odom，
会误导后续任何期待真实里程计的组件。

IMU 在 URDF 里是 `rpy="0 0 0"`，所以它报的姿态**就是**车身姿态，
不需要再复合一次静态变换（IMU 若改装则此假设失效）。

### 验证方法

读欧拉角**不算验证** —— 车摔倒时的姿态附近欧拉角难以解读且接近万向锁。

无歧义的判据是物理的：加速度计在 `base_link` 里测到重力，
把它按发布的变换旋转过去，**若坐标系正确则必然竖直**，
残余的水平分量就是误差，除以 g 直接换算成残余倾角。
见 `tools/check_level_frame.py`。

**工作区间（车身 5~10°，n=2027）：残差中位数 0.80°，p95 2.07°。**
折合 1 米处 1.4 cm，相对 4° 未补偿时的 7 cm 是够用的。

> **这个测量有个必须说明的局限。** 最初的版本用"合加速度接近 g"来剔除
> 运动样本，实测**拒绝了 0 个样本** —— 不是数据干净，是判据失效：
> 水平加速度与重力**正交相加**，横向加速 0.5 m/s² 只让模长从 9.80 变到 9.81，
> 筛不出来，但它会原封不动进入水平残差。
>
> 所以 **0.80° 是坐标系误差的上界**，其中一部分是车平衡时的真实加速度。
> 要分离两者需改用陀螺判静止，或与已知轮加速度做相关。
>
> （更早还有一版完全没有筛选，报出 67° 的"误差"，实际是操作者把车拿了起来。）

---

## 7. 下一步

风险 ①~④ 全部解除。剩下的是实现工作，不再有会推翻计划的未知数。

- **深度图 frame_id 对齐**：驱动默认发 `openni_rgb_optical_frame`，
  与 URDF 的 `camera_optical_frame` 不一致，需改参数或加静态变换
- **相机与 IMU 的时间戳对齐**：车身摆动下，深度帧要配对到**当时**的姿态。
  相机 24 Hz、IMU 145 Hz，用 `message_filters` 按时间戳近似同步
- **深度 → 障碍判据**：把点变换到 `base_link_level`，按高度分离地面与障碍，
  输出"最近障碍距离"这类**小数据**（不要把点云推过 WiFi，见下）
- 最后是避障逻辑与状态机

**可视化不要用 RViz 推原始流**：深度图 640x480 float32 @ 24 Hz 约 29 MB/s，
会淹掉 DDS 链路（README 已记过 100 Hz 的 TF 就压垮过热点）。
在树莓派上算、只发小结果；需要看图时离线拉包，或用 `foxglove_bridge`
在浏览器里看（自带压缩限流，且不需要另一台 Linux 机器）。

---

## 8. 工具选型：哪些值得引入，哪些不要碰

按对**本项目**的实际价值排，不是按名气排。

| 工具 | 结论 | 说明 |
| --- | --- | --- |
| `depth_image_proc` | **马上要用** | 深度图 + camera_info → PointCloud2，不用自己写投影 |
| PlotJuggler | **马上装** | 拖 bag 进去看时间序列和 FFT，探索阶段比写脚本快 |
| Gazebo | **做避障逻辑时引入** | 见下 |
| `robot_localization` | MVP3 的地基 | EKF 融合轮式里程计 + IMU |
| Nav2 | 更靠后 | 见下 |
| `ros2_control` | 不做 | 硬件抽象的"标准做法"，`serial_bridge` 是手搓的简化版。重构过去更正规但**不解决任何现有问题**，纯增复杂度 |
| MoveIt | **完全无关** | 机械臂运动规划。本项目没有任何关节需要规划 |
| SLAM | 不在 MVP2 范围 | 见下 |

### Gazebo：能救什么，救不了什么

**能救**：避障逻辑与状态机。仿真里可以往墙上撞一整天，不用扶车、不怕摔坏。
URDF 已有，接入成本不高。这是它对本项目最实在的价值。

**救不了**：内环整定。前几天遇到的硬问题**恰恰是仿真给不了的** ——
负载静摩擦突破 65~80 PWM、黏滑极限环、IMU 零偏两小时漂 0.86°、
340 ms 系统级停摆、前进卡死在静摩擦以下。这些全是真实世界的脏东西，
而**平衡车恰好是 sim-to-real gap 特别大的品类**，因为动力学被摩擦和延迟主导。

> 用 Gazebo 开发上层逻辑，别指望它调内环。
> 能讲清楚这个区分，比"我用了 Gazebo"本身更值钱。

**前置条件（必须先做，否则仿真里的车会乱飞）**：
当前 URDF 是给 RViz 可视化写的，只有 `<visual>`。
Gazebo 算物理需要补 **`<collision>` 几何**和**靠谱的 `<inertial>`**
（质量、惯量张量、质心位置）。工作量不大但不能跳过。
质心位置尤其关键 —— 它直接决定平衡点，而我们已经实测过真实平衡点在 7.53°，
可以拿来反推校验。

**运行环境**：Gazebo 仿真**完全不需要与树莓派通信**，自成闭环，
所以 DDS 跨机、热点带宽、IP 漂移这些问题一个都不涉及。
Windows 上建议用 **WSL2 + Ubuntu 24.04**（与树莓派同发行版、同为 ROS2 Jazzy，
代码可直接搬），不要用 VirtualBox —— 它的 3D 加速常让 Gazebo 退回软件渲染。
WSLg 能直通 GPU。注意双显卡笔记本上 WSLg 可能挑到核显。
配套版本是 Gazebo **Harmonic**（不是 Gazebo Classic）+ `ros_gz` 桥接。

### Nav2 与 SLAM：为什么不在 MVP2

**避障是无记忆的** —— 每帧独立决策。SLAM 给的是空间记忆
（"回到出发点"、"去某个房间"）。两者解决不同问题，不要混。

不在 MVP2 的四个具体理由：

1. **没有可靠里程计**（SLAM 的先验）。本机还有个特殊麻烦：
   编码器测的是轮子**相对车身**的转动，而车身自己在俯仰，
   地面位移不等于轮转角 × 半径，得先做俯仰补偿
2. **相机视野不适合 SLAM**：水平约 58°、最近 0.6 m。SLAM 通常要 360° 激光
3. **车身持续摇晃**，视觉/深度 SLAM 最怕这个（`base_link_level` 缓解了一部分）
4. **算力**：`rtabmap` 较重，与平衡环抢 CPU 有风险，
   而第 3 节刚验证过相机本身不占资源，不要把这个成果搭进去

Nav2 另有一个平衡车特有的障碍：**它的控制器默认机器人能立刻停下**，
而本机是非最小相位的（要减速得先加速），标准控制器套不上，需改写。
其 **costmap** 部分倒可单独取用做障碍表示。

**正确顺序**：`robot_localization`（里程计+IMU 融合）→ SLAM → Nav2。
顺序颠倒的话会在 SLAM 参数上耗大量时间，而问题根本不在那儿。

---

## 9. 障碍扫描：实现与实测

`balance_bot/obstacle_scan.py` 订阅深度 + IMU，投影到重力坐标系，
按高度分离地面与障碍，发布 `/obstacle/scan`（LaserScan，64 方位，29.7 Hz）
和 `/obstacle/nearest`。**点云不出树莓派** —— 只发几百个浮点数。

### 实测（手扶车身，pitch +3~+8 度）

```
基线            nearest 1.98 m   稳定在 ±0.01 m（2 米处的墙）
放入障碍物      0.65 → 0.54 → 0.53 m
移开            1.98 m           立即恢复
重复三次        0.71 / 0.71 / 0.57 m
```

响应即时，无滞后或残留。**功能验证通过。**

### 实测暴露的限制：视野里 44% 无数据

64 个方位中长期约 **28 个为 `unknown`**，而 `clear` 只有 3~4 个。
根源是无效像素（相机离地仅 9.2 cm、掠射角、深色/反光表面）。

**对避障策略的含义**：如果规则是"未知即不可通行"，车会寸步难行；
放宽则要接受风险。这个权衡必须在状态机里**显式设计**，不能含糊。
可能的缓解：抬高相机或下倾一个角度（机械改动）、
时间上累积多帧填补空洞、或对未知区域采取"减速通过"而非"停止"。

### 安全语义：unknown 与 clear 必须分开

无效像素**不是空地，是没有证据**。Astra 在 0.6 m 以内、过远、
深色、反光、掠射角表面都返回 0。某个方位的像素大多无效时，
该方位发 `NaN`（未知）而不是 `inf`（畅通）。

> **我在这上面栽了一次，值得记。** 模块开头的注释就写着这条原则，
> 但 `/obstacle/nearest` 的实现里用 `np.isfinite` 筛选候选 ——
> 它**同时排除 NaN 和 inf**，于是"全部未知"的一帧被汇总成了
> `inf`（前方无障碍）。LaserScan 本身一直是对的，只有那个标量汇总
> 把区分丢掉了。
>
> **原则在概念层被防住了，却在某个具体表达式上漏了。**
> 车躺着朝天时它报"前方畅通"——这个荒谬的输出才让问题暴露。

### 另一个 bug：无效像素的方位角是伪造的

方位角原本由**测量点**算出，而无效像素深度为 0，投影后位置就是相机偏移本身，
于是全画面的无效像素**落在同一个方位**，全堆进一个 bin，
其余 bin 的有效率分母是空的。

修正：方位角由**像素射线方向**决定 —— 它由光学决定，
不管传感器有没有返回都存在。

---

## 10. 文件索引

| 文件 | 作用 |
| --- | --- |
| `run_camera.sh`（Pi 上 `~/ros2_ws/`） | 用 Orbbec 自带 OpenNI2 启动相机驱动 |
| `tools/loadtest_camera.sh` | 相机开/关两阶段负载对照测试 |
| `~/orbbec_openni2/`（Pi 上） | Orbbec 的 OpenNI2 redist（含 `liborbbec.so`） |
| `/usr/lib/aarch64-linux-gnu/OpenNI2/Drivers/liborbbec.so.0` | 系统驱动目录里的副本（枚举够用，开流不够） |
| `balance_bot/level_frame_publisher.py` | 发布 `base_link -> base_link_level` 重力参考系 |
| `tools/check_level_frame.py` | 用重力向量验证该坐标系（含测量局限说明） |
| `balance_bot/obstacle_scan.py` | 深度 → 重力坐标系 → LaserScan 障碍扫描 |
| `tools/grab_depth.py` | 抓深度帧存 PNG + 姿态 sidecar |
| `tools/depth_geometry.py` | 离线检查一帧的三维几何是否自洽 |
| `tools/watch_scan.py` | 实时观察扫描状态（验证用） |

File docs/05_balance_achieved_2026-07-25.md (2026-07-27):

# Balance Achieved - 2026-07-25

## Result

The robot balances on its own indefinitely. The endurance run `tuneA10` held a single engaged
segment for **228.7 s** and was still balancing when the recording was stopped; it was engaged for
432.5 s of a 457.5 s recording. Pitch error stays inside about +/- 1 deg and the machine holds
position to within a quarter of a wheel revolution.

Best single-segment figures, from `tuneA9` and the first segment of `tuneA10`:

```text
pitch error RMS       0.30 deg
pitch error range     [-1.03, +1.21] deg
position wander       0.22 rev (std),  0.67 rev peak-to-peak
wheel speed RMS       61 ticks/s,  peak 267
yaw bias              0
peak PWM commanded    under 70 of 255
```

This is the first day where the body genuinely holds itself upright rather than being caught by
hand or by a wall.

## Root Cause of Every Earlier Failure

Before this run, all 29 engaged segments of `tuneA1` exited on the wheel-speed safety latch and
none on the tilt limit. The body was already stable inside +/- 2.5 deg for up to 7.8 s while the
whole robot accelerated across the floor at a steady 430 ticks/s. The angle loop was never the
problem; there was no working velocity feedback.

Two sign errors were responsible:

- `kp_v` had been used as a positive gain. It must be **negative**. To decelerate a forward-
  rolling balancing robot you must first drive the wheels forward harder so the base moves ahead
  of the centre of mass and the body pitches back; the angle loop then decelerates on its own.
  Derivation: `v > 0` needs a more positive `u`, so a more positive `err`, so
  `target = offset + trim` must shrink, so `trim < 0`, so `kp_v < 0`.
- `kd_wheel` applies `-kd_wheel * v` directly to the output, which is a naive brake. It makes the
  body pitch further forward and the angle loop immediately fights it. Leave it at 0.

`velocity_filter_alpha` also had to drop from 0.3 to 0.06. At the 100 Hz encoder rate, 0.3 puts
the outer loop cutoff near 4.8 Hz, which is faster than the inner angle loop. The outer loop must
be much slower than the inner loop.

## Best Parameter Set (run `tuneA6`)

```text
pitch_offset_deg = 7.53          capture_offset_on_engage = false
kp = 70,  ki = 0,  kd = 5
kp_v = -0.008,  ki_v = -0.005
kd_wheel = 0,  max_wheel_damping_pwm = 0
velocity_filter_alpha = 0.06     max_offset_trim_deg = 4.0
wheel_sync_kp = 0.4,  max_wheel_sync_pwm = 60
turn_velocity_filter_alpha = 0.15
pitch_rate_filter_alpha = 0.3 (default)
engage_below_deg = 3,  engage_rate_below_dps = 15
max_tilt_deg = 12,  max_wheel_velocity = 600
latch_on_fall = false            recovery_pwm = 0
deadband_pwm_fwd = 0,  deadband_pwm_bwd = 0,  deadband_ramp_deg = 0
max_pwm = 255,  motor_output_sign = 1.0
```

`latch_on_fall = false` lets the controller re-engage after the body is set upright again, so a
single recording can hold many attempts without a controller restart.

## Tuning Progression

| run | change | errRMS | velRMS | posSD (rev) | surge (s) | turnAvg | longest |
|-----|---|---|---|---|---|---|---|
| A1 | `kd_wheel = 0.3`, no velocity loop | - | - | - | - | - | 7.8 s |
| A2 | `kp_v = -0.005` sign fixed | - | - | - | - | +78 | 367 s |
| A3 | `wheel_sync_kp = 0.25` | - | - | - | - | +1 | 210 s |
| A4 | `ki_v = -0.0015`, sync 0.4 | 0.56 | 102 | 0.84 | 8.8 | +1 | 115 s |
| A5 | `kp_v -0.006`, `ki_v -0.003` | 0.51 | 82 | 0.37 | 5.2 | +1 | 134 s |
| A6 | offset 7.53, `kp_v -0.008`, `ki_v -0.005` | 0.37 | 62 | 0.25 | 5.8 | -0 | 99 s* |
| A7 | static-friction feed-forward | 1.10 | 133 | 0.44 | 4.3 | +93 | 56 s |
| A8 | A6 parameters restored | 1.03 | 135 | 0.49 | 6.4 | +86 | 9.6 s |
| -- | **loose fastener found and tightened** | | | | | | |
| A9 | A6 parameters, unchanged | **0.31** | **59** | **0.23** | 5.4 | **+1** | **70 s**† |
| A10 | offset 7.60 (reverted, see below) | 0.30 | 61 | 0.22 | 4.2 | 0 | **229 s**‡ |

\* `tuneA6` ended because recording was stopped, not because the robot fell. 153.4 s of the
155 s recording was engaged, in only two segments.

† `tuneA9` was engaged for the entire 70.3 s recording in a single segment: it never fell and
never disengaged. Pitch error stayed inside [-0.95, +1.00] deg, peak wheel speed was 239 ticks/s
against 606 in `tuneA6`, and no sample in the whole run commanded more than 70 PWM.

‡ `tuneA10` is the endurance run: 228.7 s in one segment, still balancing when recording stopped,
432.5 s engaged out of 457.5 s. Its figures in the table are from the first 88 s segment. Two
short segments in the middle of that run show `turnAvg` 184 and errRMS 1.37; those are external
disturbances, not controller behaviour.

## What Was Never the Problem

Recorded so these are not re-tested:

- `pitch_offset_deg` beyond the 7.53 value. It was swept by trial and error across earlier
  sessions at great cost; the mean-pitch method settles it in one run.
- `motor_output_sign`. Confirmed 1.0.
- Motor or gearbox asymmetry. An open-loop free-spin test measured 1590-1600 ticks/s in both
  directions.
- The angle inner loop. `kp = 70`, `kd = 5` were inherited and never needed changing; every
  failure through `tuneA1` was a wheel-speed runaway, not an angle-loop failure.
- `kd_wheel` and `max_wheel_damping_pwm`. Structurally the wrong tool, see above. Leave at 0.
- Deadband feed-forward. Leave at 0.

## Next Stage

The angle loop, the velocity loop and the position loop are all closed and stable, so balance
tuning is finished. The next piece of work is accepting motion commands, which means feeding a
non-zero velocity target into the outer loop instead of the implicit zero, and adding a yaw-rate
target alongside `wheel_sync_kp` so the robot can be steered. Neither is a tuning task.

## How `pitch_offset_deg` Was Refined to 7.53

Do not sweep this parameter by trial and error. While the robot balances with a mean wheel speed
of zero, the mean pitch over a long engaged segment *is* the true balance point. Two independent
runs agreed to within 0.03 deg:

```text
tuneA4 mean pitch = 7.528 deg
tuneA5 mean pitch = 7.554 deg
```

Estimating instead from the outer-loop trim gave inconsistent answers (7.46 vs 8.21 deg) because
the velocity integral was clamped; the mean-pitch method is the reliable one.

**Stop refining at this resolution.** `tuneA10` tried 7.60 and it was slightly worse: the integral
mean rose from +38 to +184 and started clamping again (0.0 to 2.1 percent). Mean pitch between the
two runs differed by 0.27 deg, which is larger than the 0.07 deg change being tested, so anything
below about 0.2 deg is run-to-run noise. Use the integral mean, not mean pitch, to judge offset at
this scale: it should sit near zero and never clamp. 7.53 is the value to keep.

The correction was confirmed by its effect on the integral, which had been silently spending its
range compensating the offset error:

```text
velocity_integral mean:    -322 (A5, offset 7.20)  ->   -49 (A6, offset 7.53)
velocity_integral clamped:  8.5% (A5)              ->  0.0% (A6)
```

## A Loose Fastener Masqueraded as a Tuning Problem

Runs `tuneA7` and `tuneA8` both degraded badly, and the cause was mechanical, not a parameter.

`tuneA7` enabled static-friction feed-forward and every metric got worse, with yaw regressing
hardest: `turnAvg` went from about 0 to +93, `|turn|` peaks to 1088. The obvious reading was that
the feed-forward caused it. **That reading was wrong.** `tuneA8` reverted every deadband
parameter to zero and the yaw bias stayed (`turnAvg` +86, `|turn|max` 1207), while engaged time
collapsed to 11.3 s out of 84.4 s.

Three independent signals pointed at hardware rather than gains:

```text
mean pitch while balancing:  7.528 (A4)  7.554 (A5)  7.673 (A6)  8.176 (A8)
turnAvg:                     -0 (A6)     +93 (A7)    +86 (A8, deadband already reverted)
engaged fraction:            153/155 s (A6)          11.3/84.4 s (A8)
```

A single loose fastener explains all three at once: a shifted balance point, a left/right
asymmetry, and total loss of performance. This project has a documented history of the IMU
mounting screw working loose. Tightening the hardware restored everything.

`tuneA9` re-ran the `tuneA6` parameters unchanged after the fix and beat `tuneA6` on every
metric, which means the hardware had already been degrading during `tuneA6` itself.

**Rule going forward:** when several unrelated metrics degrade at once and a parameter revert does
not restore them, stop tuning and inspect the hardware. Do not attribute it to the most recent
parameter change.

## Static-Friction Feed-Forward: Verdict Deferred

The `tuneA7` feed-forward test is inconclusive because it overlapped the loose fastener. What the
data does show is that it worked mechanically: the wheels-moving fraction at `|pwm|` 100-150 rose
from 92.9 to 97.0 percent, and samples in the sticky 1-40 band fell from 11033 to 2924.

It is probably not needed at all. After the hardware fix, `tuneA9` never commanded more than
70 PWM for the entire recording and peak wheel speed dropped from 606 to 239 ticks/s, so the
stick-slip lurch largely disappeared on its own.

If it is ever revisited, note the structural defect: the assist is added to the common-mode `u`,
while the bridge maps `left = u - sync` and `right = u + sync`. Since the two wheels have
different breakaway thresholds, a common-mode assist can free one wheel and not the other, which
is a yaw disturbance that `wheel_sync_kp` cannot correct because its own differential command is
subject to the same stiction. Compensation must be applied **per wheel after the differential
split**. The `deadband_dither_hz` path has the same defect as written.

## Breakaway Measurement Note

Loaded breakaway measured from closed-loop bags is roughly symmetric and has no sharp threshold:
about 60 percent of held commands move the wheels at 25-35 PWM, only about 50 percent at 45-55,
and 80-85 percent at 65-80.

An earlier reading of this data claimed stiction was not a limiting factor. That was wrong: the
test counted samples where PWM was still ramping, which made breakaway look far lower than it is.
Any breakaway test must exclude samples where the command is still changing.

## Confirmed Facts

- `pitch_offset_deg = 7.20` is correct. Error ranges in `tuneA2` are symmetric about zero and
  falls occur in both directions, so it needs no further sweeping.
- `motor_output_sign = 1.0` is correct. Do not flip it.
- Static friction is not a limiting factor. At commanded `|pwm|` of 1-40 the wheels were already
  turning 72 percent of the time, so the deadband feed-forward can stay at 0.
- IMU now publishes at about **147 Hz**, not the 303 Hz recorded on 2026-07-24. Encoders are at
  about 99 Hz. A one-pole filter alpha therefore maps to roughly half the cutoff frequency it did
  before, so `pitch_rate_filter_alpha` and `velocity_filter_alpha` are not comparable across the
  two dates.
- Arduino firmware now has a command watchdog (`CMD_TIMEOUT_MS`), so an undelivered stop command
  no longer leaves the wheels latched on.

## Open Issue

The robot balances but rotates in place. Yaw is unregulated: `turn_velocity = left_v - right_v`
sits at a persistent bias near +100 ticks/s with peaks to 730, meaning the left wheel consistently
outruns the right. `wheel_sync_kp` exists for this and was still 0 during `tuneA2`.

Sign check against `serial_bridge`: `left_pwm = (linear - angular) * 100` and
`right_pwm = (linear + angular) * 100`, with `angular * 100 = sync_correction`. A positive
`turn_velocity` therefore needs a positive `sync_correction`, so **`wheel_sync_kp` is positive**.
The correction is equal and opposite on the two sides, so it does not change the mean forward
torque and does not disturb the balance loop.

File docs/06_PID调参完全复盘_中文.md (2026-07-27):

# 两轮自平衡车 PID 调参完全复盘

> 记录日期：2026-07-25
> 结果：单段连续平衡 **228.7 秒**（停止录制时仍在站立），车身角度全程 ±1°，原地位置守在 1/4 圈以内
> 目标读者：本项目作者本人 + 面试准备

这份文档不是参数表，是**推导过程**。每一个参数值都附带"为什么是这个数"，
以及"用什么数据判断它对不对"。参数表在 `config/balance_params.yaml`。

---

## 目录

1. [硬件与软件架构](#1-硬件与软件架构)
2. [控制结构：为什么必须是串级](#2-控制结构为什么必须是串级)
3. [核心理论：平衡车的非最小相位特性](#3-核心理论平衡车的非最小相位特性)
4. [调参方法论：怎么摆脱瞎试](#4-调参方法论怎么摆脱瞎试)
5. [实战全过程 A1 → A11](#5-实战全过程-a1--a11)
6. [踩过的六个坑](#6-踩过的六个坑)
7. [遗留问题与后续思路](#7-遗留问题与后续思路)
8. [面试准备](#8-面试准备)

---

## 1. 硬件与软件架构

### 1.1 硬件链路

```
HFI-A9 IMU ──USB串口──┐
                      ├── Raspberry Pi 5 (ROS2 Jazzy)
Arduino Mega ─USB串口─┘
     │
     ├── 双路电机驱动 (PWM)
     └── 双路正交编码器
```

### 1.2 ROS2 节点与话题

| 节点 | 职责 | 发布 | 订阅 |
|---|---|---|---|
| `hfi_imu` | IMU 驱动 | `/imu/data` (~150 Hz) | — |
| `serial_bridge` | 串口协议桥 | `/wheel/encoders` (~100 Hz) | `/cmd_vel` |
| `balance_controller` | 控制器 | `/cmd_vel` | `/imu/data`, `/wheel/encoders` |

**关键点：控制周期由 IMU 回调驱动**，不用定时器。这样 D 项的差分和实际采样严格对齐，
没有定时器与传感器之间的相位误差。

```python
self.create_subscription(Imu, '/imu/data', self._imu_cb, 10)
# 所有控制计算都在 _imu_cb 里完成
```

### 1.3 姿态角的提取

IMU 给的是四元数，pitch 用标准公式提取：

```python
sinp = max(-1.0, min(1.0, 2.0 * (w * y - z * x)))
pitch = math.degrees(math.asin(sinp))
```

`max/min` 的钳位是必须的——浮点误差会让 `sinp` 略微超出 [-1, 1]，`asin` 直接抛异常。

### 1.4 PWM 的下发路径（这条链路的符号约定，后面处处要用）

控制器发布 `Twist`：

```python
def _send_pwm(self, u, sync_correction=0.0):
    cmd = Twist()
    cmd.linear.x  = u / 100.0                # 共模：前后
    cmd.angular.z = sync_correction / 100.0  # 差模：偏航
    self.cmd_pub.publish(cmd)
```

`serial_bridge` 拆成左右轮：

```python
left_pwm  = int((linear - angular) * 100)
right_pwm = int((linear + angular) * 100)
```

即 **`left = u - sync`，`right = u + sync`**。这个式子在第 5.3 节（偏航）和
第 6.5 节（摩擦补偿为什么失败）里都是关键。

### 1.5 编码器轮速的计算

左右编码器镜像安装，计数天生反向，所以右轮要取负：

```python
left_v  =  dl / dt
right_v = -dr / dt
raw_v = (left_v + right_v) / 2.0   # 共模：前进速度
turn  =  left_v - right_v          # 差模：偏航速度
```

**共模用于速度/位置环，差模用于偏航环。两者完全解耦**，
因为差模是等量反向叠加的，不改变平均前后扭矩。

---

## 2. 控制结构：为什么必须是串级

### 2.1 只有角度环会发生什么

最直觉的做法是：测倾角 → PID → 驱动轮子。这**确实能让车身站直**，但会出大问题。

第一轮实测 `tuneA1`（kp=70, kd=5，无速度环）的结果：

```
29 段接管，退出原因 100% 是"轮速超限"，一次都没有因为倾角摔倒
段0: 7.15s   段3: 7.76s   err 全程在 [-1.7, +2.5]° 内，17 次过零
轮速末值稳定在 ±430 ticks/s
```

**它不是倒了，是一边站着一边一路加速跑掉了。**

原因：角度环只有一个目标——让 `pitch = offset`。如果 `offset` 哪怕差 0.1°，
车身就会稳定地保持 0.1° 的倾斜，而一个持续倾斜的平衡车会**持续加速**。
角度环对此毫无察觉，因为它的误差是零。

> 这是理解整个项目的第一个关键认识：
> **车身角度稳定 ≠ 车稳定。角度环是欠驱动系统的内环，它无法约束位置和速度。**

### 2.2 四个环的分工

```
                 ┌──────────── 位置环 (ki_v) ────────────┐
                 │        ┌──── 速度环 (kp_v) ────┐      │
                 ↓        ↓                       │      │
目标位置=0 ──→ offset_trim ──→ 目标倾角 ──→ 角度环(kp/kd) ──→ u ──┬──→ 左轮 u - sync
                                              ↑                  └──→ 右轮 u + sync
                                          IMU pitch                        ↑
                                                                    偏航环 (wheel_sync_kp)
                                                                           ↑
                                                                    编码器差模轮速
```

代码里的实现（`balance_controller.py::_imu_cb`）：

```python
# 外环：速度 + 位置 → 修正目标倾角
offset_trim = kp_v * self.wheel_velocity + ki_v * self.velocity_integral
offset_trim = max(-max_offset_trim, min(max_offset_trim, offset_trim))

err = pitch - (effective_offset + offset_trim)   # ← 外环通过改目标角来指挥内环

# 内环：角度 PID
u = kp * err + ki * self.integral + kd * rate_for_control

# 偏航环：差模，独立叠加
sync_correction = wheel_sync_kp * self.turn_velocity
```

**关键理解：外环不直接输出 PWM，它输出的是"目标倾角的修正量"。**
外环通过让车身有意识地前倾/后仰，间接指挥内环去改变速度。这是串级控制的精髓。

### 2.3 一个容易被忽略的事实：`ki_v` 其实是位置环

```python
self.velocity_integral += self.wheel_velocity * dt
```

**速度的积分就是位置**。所以：

| 参数 | 名义身份 | 实际身份 |
|---|---|---|
| `kp_v` | 速度环比例 | **位置环的微分项（阻尼）** |
| `ki_v` | 速度环积分 | **位置环的比例项（刚度）** |

这个认识非常有用——它把"速度环怎么调"这个模糊问题，转化成了
"位置 PD 环的刚度和阻尼怎么配"这个标准的二阶系统问题。第 5.5 节全靠这个认识推进。

---

## 3. 核心理论：平衡车的非最小相位特性

**这是整个项目最重要的一个物理认识，也是最容易搞错符号的地方。**

### 3.1 反直觉的现象

问题：车正在以 v > 0 向前滚，想让它停下来，该怎么办？

**错误答案**：给轮子反向 PWM 刹车。
结果：轮子减速了，但车身因为惯性继续前冲 → 车身**更加前倾** →
角度环立刻加大前进油门去"救"它 → 车反而加速了。刹车动作被平衡环彻底抵消。

**正确答案**：先给轮子**更大的前进 PWM**。
机理：轮子冲到重心前面 → 车身被"抽"得向后仰 →
车身后仰后，角度环为了追这个后仰的重心，自己会输出反向 PWM → 车减速停下。

> **要减速，必须先加速。这就是非最小相位（non-minimum phase）系统的典型特征：
> 系统对控制输入的初始响应方向，与最终稳态响应方向相反。**

物理上的根源：这是一个**欠驱动系统**——一个执行器（轮子扭矩）要同时控制
两个自由度（车身角度 + 车体位置），只能通过牺牲一个去换另一个。

### 3.2 符号的严格推导

代码里的符号约定：`pitch` 正 = 前倾；前倾需要正向（前进）PWM 去追重心。

已知：
```python
err = pitch - (offset + trim)
u   = kp * err + ...          # kp > 0
```

推导（v > 0，想减速）：

| 步骤 | 结论 |
|---|---|
| 1. 要减速 | 需要一个**更大的前进 PWM** 的瞬态 |
| 2. u 要更正 | 因为 `u = kp·err`，所以 `err` 要更正 |
| 3. err 要更正 | 因为 `err = pitch - (offset + trim)`，所以 `(offset + trim)` 要更小 |
| 4. 目标要更小 | 所以 `trim` 要为**负** |
| 5. trim = kp_v · v，而 v > 0 | 所以 **`kp_v` 必须为负** |

### 3.3 用微分方程独立验算

设外环修正到加速度的传递为 `dv/dt = K'·trim`（K' > 0）。

> 这里 K' 的符号也要小心：`trim` 为负 → 目标角变小 → 车身最终稳定在**后仰**状态
> → 后仰的平衡车向**后**加速 → `dv/dt` 为负。所以 `dv/dt` 与 `trim` **同号**，K' > 0。

代入 `trim = kp_v·v + ki_v·x`，其中 `x = ∫v dt`：

```
dv/dt = K'·(kp_v·v + ki_v·x)
d²x/dt² - K'·kp_v·(dx/dt) - K'·ki_v·x = 0
```

特征方程：

```
s² - K'·kp_v·s - K'·ki_v = 0
```

二阶系统稳定要求所有系数为正：

```
-K'·kp_v > 0  →  kp_v < 0   ✓
-K'·ki_v > 0  →  ki_v < 0   ✓
```

**两个外环增益都必须取负值。** 两条独立路径（物理直觉 + 微分方程）结论一致。

### 3.4 历史教训

翻项目 `logs/` 目录，早期文件名是 `cmd_vel_kpv001.log`、`cmd_vel_kpv004.log`，
即 `kp_v = +0.01`、`+0.04`。**符号是反的**。

正的 `kp_v` 意味着：车向前跑 → 目标角变大 → err 变小 → 前进 PWM 减小 →
车身更前倾 → 更用力前进。这是**正反馈**，只会让跑飞更快。

这解释了为什么之前速度环怎么调都没用——不是增益大小的问题，是方向从一开始就错了。

---

## 4. 调参方法论：怎么摆脱瞎试

这一节是这个项目最值得写进简历的部分。**核心思想是：把调参从"试参数"变成"做测量"。**

### 4.1 工作流

```
设参数 (ros2 param set)
   → 录包 (ros2 bag record /imu/data /cmd_vel /wheel/encoders)
   → 拉回本地 (scp)
   → 离线复现控制器状态机，算指标
   → 从指标推下一组参数
```

关键是最后两步。**不靠肉眼看车，靠指标说话。**

### 4.2 离线复现状态机

录包里没有"控制器当时是否接管"这个信息，但因为知道全部参数，可以精确复现它的状态机：

```python
# 与 balance_controller 的判定逻辑严格一致
err = pitch - offset
engaged = False
for i in range(len(err)):
    if engaged:
        if abs(vel[i]) > max_wheel_v:
            segments.append((start, i, 'WHEEL'))   # 轮速保护切断
            engaged = False
        elif abs(err[i]) > max_tilt:
            segments.append((start, i, 'TILT'))    # 倾角超限，真摔了
            engaged = False
    elif abs(err[i]) < engage_below and abs(rate[i]) < engage_rate_below:
        engaged = True
        start = i
```

**`exit` 原因这一列价值极高**——它直接告诉你失败模式是什么：

- 全是 `TILT` → 角度环兜不住，调 kp/kd
- 全是 `WHEEL` → 角度环没问题，是速度/位置失控（`tuneA1` 就是这样）
- `END` → 录制结束时它还站着（最好的结果）

### 4.3 关键指标定义

| 指标 | 定义 | 诊断什么 |
|---|---|---|
| `dur` | 单段接管时长 | 总体好坏 |
| `exit` | 退出原因 | **失败模式分类** |
| `errRMS` | 角度误差均方根 | 角度环品质 |
| `velMean` | 平均轮速（**带符号**） | 单向漂移 |
| `velRMS` | 轮速均方根 | 动作剧烈程度 |
| `posSD` / `posPP` | 位置（速度积分）标准差 / 峰峰值 | 位置守得住不 |
| `surge_s` | 位置摆动周期 | 位置环阻尼 |
| `turnAvg` | 平均差模轮速 | **偏航偏置** |
| `sat%` | PWM 饱和占比 | 执行器够不够用 |
| 积分均值 / 限幅% | `velocity_integral` 统计 | **零点准不准** |

**`velMean` 必须带符号**——绝对值会把"来回摆"和"单向跑"混为一谈，这两者的对策完全相反。

### 4.4 三个自制的诊断脚本

| 脚本 | 作用 | 解决了什么问题 |
|---|---|---|
| `analyze_run.py` | 复现状态机 + 全套指标 | 主力工具 |
| `true_offset.py` | 从平衡数据反推真实平衡点 | 让 offset 标定从"扫参数"变成"一次测量" |
| `breakaway.py` | 测负载下的静摩擦突破电压 | 定位 stick-slip |
| `jerk_trace.py` | 打印极值时刻前后 2 秒的原始逐点轨迹 | **聚合统计看不出的问题** |

**`jerk_trace.py` 的价值要特别强调**：第 5.7 节那个 stick-slip 问题，
在任何聚合统计里都是隐形的，只有把原始逐点数据打出来才看得见。

> **教训：当聚合指标解释不了现象时，一定要去看原始波形。**

### 4.5 一个统计陷阱（我自己踩了）

第一次测静摩擦，我的判据是"轮子停着时给了 PWM，多久后开始转"，结论是
"10~20 PWM 就有 98% 能起步，静摩擦不是瓶颈"。**这个结论是错的。**

错在样本里混进了大量**PWM 正在上升**的时刻：记录的是"起步瞬间 PWM=15"，
但实际让它起步的是紧接着的 PWM=80。修正方法是加一个"指令已稳定"的过滤：

```python
# 指令必须与 100ms 前的值相差不超过 15 PWM，排除正在爬升的样本
lag = 10   # 编码器 100Hz，10 个样本 = 100ms
held = np.zeros(len(p), dtype=bool)
held[lag:] = np.abs(p[lag:] - p[:-lag]) < 15.0
```

加了过滤后，真实结论完全反转：突破电压在 **65~80 PWM** 量级。

> **教训：测阈值时必须排除瞬态样本，否则会系统性低估阈值。**

### 4.6 让一次录包包含几十次尝试

```python
self.declare_parameter('latch_on_fall', True)
```

默认摔倒后锁存，必须重启控制器才能再接管——调参时这非常低效。
调试期设成 `false`，摔了以后人扶正就自动重新接管，**一个 200 秒的录包能装下几十次尝试**，
统计意义强得多。

（无人值守运行时应该改回 `true`，避免一次摔倒后反复自动上电。）

---

## 5. 实战全过程 A1 → A11

### 5.0 起点状态

接手时的已知条件（来自 `docs/04_balance_tuning_pause_2026-07-24.md`）：

```
pitch_offset_deg = 7.20    (静态标定，std 0.11°，2374 采样)
kp = 70, kd = 5
motor_output_sign = 1.0    (已实测确认，不要翻)
最后一次测试：轮速冲到 +271 ticks/s 被安全锁存切断
```

### 5.1 A1：确认失败模式 —— 不是角度环的问题

**改动**：启用 `kd_wheel = 0.3`（轮速直接阻尼），`max_tilt` 5→12，`latch_on_fall` 关闭。

**结果**：

```
29 段接管，退出原因 100% 是 WHEEL，0 次 TILT
最好 7.76s，err 全程 [-1.72, +2.54]°
轮速末值稳定 ±430 ticks/s
```

**结论**：`kd_wheel` 完全没用，而且方向本来就是错的。

```python
wheel_damping = -kd_wheel * self.wheel_velocity   # v>0 时减小前进PWM = 直接刹车
u += wheel_damping
```

这正是第 3.1 节说的"错误答案"——直接刹车会让车身更前倾，角度环立刻反向加油门对抗。
**`kd_wheel` 是个结构性错误的工具，永久置 0。**

真正的收获是失败模式的确诊：**0 次 TILT 说明角度环从来就不是问题**，
前面所有对 kp/kd 的调整都调错了地方。

### 5.2 A2：符号修正 —— 从 7 秒到 367 秒

**改动**（单变量）：

```
kp_v: 0 → -0.005              # 符号见第 3.2 节推导
kd_wheel: 0.3 → 0             # 关掉错误的工具
velocity_filter_alpha: 0.3 → 0.06
max_offset_trim_deg: 4.0
```

**关于 `velocity_filter_alpha`**：一阶低通的截止频率 `fc ≈ α·fs/(2π)`。
编码器 100 Hz 时，α=0.3 → fc ≈ 4.8 Hz，**比角度内环还快**。
串级控制要求外环带宽远低于内环（一般 5~10 倍），否则两环互相打架。
降到 0.06 → fc ≈ 0.95 Hz，拉开了。

**结果**：

```
最长段 367 秒（此前最好 7.8 秒）
但 turnAvg = +78 → 原地转圈
```

**跑飞问题一次性解决**。这一轮证明了：前面几天的困境不是"参数没调好"，
而是**一个符号错误**。

### 5.3 A3：偏航同步 —— 差模控制

**现象**：能站很久，但原地转圈。`turnAvg` 长期 +78~+100（左轮持续比右轮快）。

**符号推导**：
- `turn = left_v - right_v`，turn > 0 表示左轮快
- 要纠正，需要**减小左轮、增大右轮**
- 由 `left = u - sync`、`right = u + sync`，减小左 / 增大右 ⇒ **sync 增大**
- `sync = wheel_sync_kp · turn`，turn > 0 时要 sync > 0 ⇒ **`wheel_sync_kp` 取正**

**改动**：`wheel_sync_kp = 0.25`，`max_wheel_sync_pwm = 60`，`max_wheel_velocity` 400→600。

**结果**：

```
turnAvg:  +78  →  +1 / -0 / -3      系统性偏航偏置归零
最长段 209.7s
但 velMean = -31 ticks/s → 慢速单向漂移
```

**为什么偏航环不干扰平衡环**：差模是等量反向叠加的（一个 -sync 一个 +sync），
左右轮 PWM 之和不变，即平均前后扭矩不变。**共模与差模天然解耦。**

### 5.4 A4：位置积分 —— 消灭稳态漂移

**现象**：`velMean = -31 ticks/s` 稳定的单向慢走，刹不住。

**原理**：纯 P 速度环存在**固有稳态误差**。设真实平衡点与配置的 offset 差 δ，
则稳态时必须有 `kp_v · v_ss = δ`，即 `v_ss = δ / kp_v ≠ 0`。
P 项在数学上不可能把速度归零——**必须引入积分项**。

实测吻合：`-0.005 × (-31) = +0.155°`，正好就是那个平衡点偏差。

**改动**：`ki_v = -0.0015`（符号与 kp_v 同号），`wheel_sync_kp` 0.25→0.4。

**幅值怎么定**：希望 v = -31 持续约 3.5 秒能积出所需的 0.155° 修正：

```
integral ≈ -31 × 3.5 = -108.5
ki_v = 0.155 / 108.5 ≈ 0.0014  →  取 -0.0015
```

安全性检查：`velocity_integral` 硬钳在 ±500，所以积分项贡献封顶
`0.0015 × 500 = 0.75°`，跑不飞。

**结果**：

```
velMean:  -31  →  +5 / -8       漂移消灭
errRMS 0.56°，最长段 114.7s
新现象：位置以 8.8 秒周期来回摆（用户描述："后退一段刹住，前进一段刹住"）
```

### 5.5 A5：位置环刚度 —— 用二阶系统理论定方向

**现象**：8.8 秒周期的位置来回摆，位置峰峰值 3.6 圈。

**先判断是不是线性欠阻尼**（决定了该加阻尼还是加刚度）：

```
观测周期 8.8s  →  ω_n ≈ 2π/8.8 ≈ 0.785 rad/s
由 ω_n² = -K'·ki_v  →  K' = 0.616 / 0.0015 ≈ 411
由 2ζω_n = -K'·kp_v  →  ζ = (411 × 0.005) / (2 × 0.785) ≈ 1.31
```

**ζ = 1.31 是过阻尼**。过阻尼的线性二阶系统**不会振荡**。
所以这个 8 秒摆动不是 PID 参数问题，另有原因；
同时也意味着**阻尼有富余，可以拿来换刚度**。

两个嫌疑：静摩擦极限环 / 积分限幅。查数据：

```
velocity_integral 撞 ±500 限幅：7.3% 样本，|I|>400：13.6%
```

积分确实在顶天花板——摆到极端位置时回复力被削顶、不再随位移增长，于是过冲。

**改动**：`ki_v` -0.0015 → **-0.003**（刚度翻倍），`kp_v` -0.005 → **-0.006**（补阻尼）。

预测：`ω_n ∝ √ki_v` → 周期 8.8 / √2 ≈ 6.2s；`ζ ∝ kp_v/√ki_v` → 1.31 → 1.14。

**结果**（预测基本命中）：

```
周期     8.8s  →  5.16s
posSD    0.84  →  0.37 圈
posPP    3.61  →  1.42 圈
errRMS   0.56  →  0.51°
最长段   114.7 → 134.1s
```

### 5.6 A6：零点精修 —— 从"扫参数"到"一次测量"

**现象**：刚度加倍后，`|I|>400` 的占比反而从 13.6% 涨到 **31.6%**，积分长期贴着天花板。

**推理**：稳态时速度为零，`trim = ki_v · I`。积分被长期顶住，说明它在
**补偿一个固定的直流偏差**——也就是 `pitch_offset_deg` 本身偏了，白白吃掉积分行程。

**怎么算出真实零点**（这是本项目最有价值的一个技巧）：

> **当车在平衡且长时间平均轮速为零时，车身的平均 pitch 就是真实机械平衡点。**

理由：平均轮速为零 ⇒ 长期没有净加速度 ⇒ 车身平均姿态必然就是重力力矩为零的姿态。

```python
# true_offset.py 的核心：直接取长段的平均 pitch
mean_pitch = pitch[engaged_and_settled].mean()
```

两轮独立数据高度一致：

```
tuneA4 平均 pitch = 7.528°
tuneA5 平均 pitch = 7.554°     ← 差 0.03°
```

而用外环 trim 反推的结果是不可信的（A4 给 7.46°，A5 给 8.21°，差 0.75°），
因为积分被限幅削过。**平均 pitch 法才是可靠的那个。**

**改动**：`pitch_offset_deg` 7.20 → **7.53**，同时 `ki_v` → -0.005，`kp_v` → -0.008。

**结果**：

```
积分均值:   -322  →  -49        不再长期补偿零点
积分限幅:   8.5%  →  0.0%       完全消失
errRMS      0.51  →  0.37°
posSD       0.37  →  0.25 圈
接管占比    153.4s / 155s（仅 2 段）
```

> **这一条对面试特别有说服力**：offset 这个参数在此前的会话里被反复试错扫描、
> 耗费了大量时间；用这个方法，一次录包就定死了，而且有独立的验证判据（积分均值→0、限幅→0%）。

### 5.7 A7：静摩擦补偿的尝试与失败

**现象**：偶尔一次向前"抽动"。用 `jerk_trace.py` 打出原始轨迹：

```
 t_rel   pitch    err    rate    pwm    vel
 -1.67    7.53   0.00   -0.7    -45      0   ← 持续给 -45 PWM，轮子纹丝不动
 -1.40    7.48  -0.05    0.1    -50      0
 -1.08    7.60   0.07    1.1    -34      0   ← 轮子卡住期间，车身开始自己前倾
 -0.82    8.32   0.79    6.0     40     26
 -0.35    9.06   1.53  -14.5    116    166   ← PWM 追到 116 才彻底挣脱
  0.05    5.46  -2.07  -26.8    -69    341   ← 挣脱后暴冲，车身反甩到 -2.07°
```

**教科书级的 stick-slip（黏滑）极限环**：
卡住 → 车身自己倾 → PWM 一路追高 → 突然挣脱 → 暴冲过冲。

用 `breakaway.py`（含 4.5 节的"指令已稳定"过滤）测负载下的突破电压：

```
        FWD 移动率   BWD 移动率
25-35     60.5%       63.6%
45-55     50.3%       47.9%     ← 一半概率推不动
65-80     80.4%       84.9%
```

平衡时 `|u|` 大部分时间落在 25~55 这个"掷硬币"区间。

**改动**：启用 `deadband_output_ramp` 通路：

```python
effort_scale = min(1.0, abs(u) / deadband_output_ramp)          # 按PID输出大小给助力
speed_scale  = max(0.0, 1.0 - abs(wheel_velocity) / deadband_velocity)  # 转起来后褪去
u += deadband_fwd * effort_scale * speed_scale
```

参数：`deadband_pwm_fwd/bwd=35`，`output_ramp=20`，`velocity_threshold=80`，
`deadband_err_deg=1.0 → 0.05`（默认要等车身倾过 1° 才补偿，那正是要避免的）。

**结果：全线退步，偏航退得最狠。**

```
errRMS   0.37 → 1.10°
turnAvg  -0   → +93
|turn|max 235 → 1088
```

**机理分析**（详见第 6.5 节）：助力只加在共模 `u` 上，而左右轮突破电压不同。
原来两轮大多**一起卡住**（对称，不产生偏航）；加了助力后共模被抬进
"一个挣脱了另一个还卡着"的区间，直接变成大差速。

### 5.8 A8：回退失败 —— 真凶是硬件

把 A7 的死区参数全部清零，**完全回到 A6 配置**。结果不但没恢复，反而更差：

```
turnAvg  +86（死区参数已全清零，偏航依然在）
接管     11.3s / 84.4s
```

三个独立信号同时指向硬件：

```
平衡时平均 pitch:  7.528(A4)  7.554(A5)  7.673(A6)  8.176(A8)   ← 零点整体漂移
turnAvg:           -0(A6)     +93(A7)    +86(A8)                ← 撤销后偏航仍在
接管占比:          153/155s(A6)          11.3/84.4s(A8)         ← 全面崩溃
```

**一个松动的紧固件能同时解释这三条**：姿态基准改变（零点漂移）+
轮系不平行（左右不对称）+ 整体失效。而且这个项目**有前科**——
之前出现过"IMU 螺丝松动掉了"。

紧固硬件后，A9 用**完全相同的 A6 参数**跑出了比 A6 更好的结果——
说明硬件在 A6 期间就已经在松了。

> **这一条是最重要的工程教训，见第 6.6 节。**

### 5.9 A9 / A10 / A11：验证与固化

**A9**（紧固后，A6 参数原封不动）：

```
1 段接管覆盖整个 70.3 秒录包 —— 全程没摔、没脱离
errRMS 0.31°，误差范围 [-0.95, +1.00]°
velMax 606 → 239（stick-slip 暴冲基本消失）
整个录包 PWM 从未超过 70（满量程 255）
```

**A10**（耐久 + 零点微调到 7.60）：

```
最长段 228.7 秒（停录制时仍在站立），接管 432.5s / 457.5s
但零点微调是退步：积分均值 +38 → +184，限幅 0.0% → 2.1%
```

**关于零点该精修到什么程度**：A9 和 A10 的平均 pitch 分别是 7.596 和 7.324，
**差 0.27°，比我调的那 0.07° 还大**——这个尺度上已经是 run-to-run 噪声了。

> **判据升级**：零点精修到 0.2° 以下时，不要再用平均 pitch（噪声太大），
> 改用**积分均值**——它应该接近 0 且永不限幅。据此 7.53 明确优于 7.60，回退。

**A11**（从配置文件启动的最终验证）：

```
最长段 145.6s，接管 162.5s / 200s
posSD 0.25 圈、velRMS 62、turnAvg +1、积分限幅 0.0%   ← 与 A9/A10 完全一致
```

### 5.10 全程指标汇总

| 轮次 | 改动 | errRMS | velRMS | posSD(圈) | 摆动周期 | turnAvg | 最长段 |
|---|---|---|---|---|---|---|---|
| A1 | `kd_wheel=0.3`，无速度环 | — | — | — | — | — | 7.8 s |
| A2 | **`kp_v=-0.005` 符号修正** | — | — | — | — | +78 | **367 s** |
| A3 | `wheel_sync_kp=0.25` | — | — | — | — | **+1** | 210 s |
| A4 | `ki_v=-0.0015` | 0.56 | 102 | 0.84 | 8.8 s | +1 | 115 s |
| A5 | `kp_v -0.006`, `ki_v -0.003` | 0.51 | 82 | 0.37 | 5.2 s | +1 | 134 s |
| A6 | **offset 7.53**, `ki_v -0.005` | 0.37 | 62 | 0.25 | 5.8 s | -0 | 99 s |
| A7 | 静摩擦补偿 | 1.10 | 133 | 0.44 | 4.3 s | +93 | 56 s |
| A8 | 回退到 A6 参数 | 1.03 | 135 | 0.49 | 6.4 s | +86 | 9.6 s |
| — | **发现并紧固松动的硬件** | | | | | | |
| A9 | A6 参数，未改动 | **0.31** | 59 | 0.23 | 5.4 s | +1 | 70 s |
| A10 | 耐久测试 | 0.30 | 61 | **0.22** | 4.2 s | 0 | **229 s** |
| A11 | 从配置文件启动 | 0.50 | 62 | 0.25 | 5.6 s | +1 | 146 s |

### 5.11 最终参数与固化

完整参数见 `config/balance_params.yaml`。核心部分：

```yaml
pitch_offset_deg: 7.53      # 平均pitch法标定，判据=积分均值≈0且不限幅
kp: 70.0,  ki: 0.0,  kd: 5.0            # 角度内环，全程未改动
kp_v: -0.008,  ki_v: -0.005             # 外环，两者必须为负
velocity_filter_alpha: 0.06             # 外环带宽必须远低于内环
kd_wheel: 0.0                           # 结构性错误的工具，永久置0
wheel_sync_kp: 0.4                      # 偏航差模，取正
deadband_pwm_fwd/bwd: 0.0               # 摩擦补偿，共模实现有缺陷，置0
```

启动：

```bash
ros2 launch balance_bot balance.launch.py
```

> **参数必须落盘**。整个调参过程都是 `ros2 param set` 打进内存的，
> 节点一重启就全没了。收尾时务必固化到 YAML + launch，并**实际重启验证一次**
> 参数确实是从文件加载的，而不是内存残留。

---

## 6. 踩过的六个坑

### 6.1 符号错误（`kp_v`）—— 最贵的一个

**表现**：速度环怎么调都没用，加大增益只会让跑飞更快。
**根因**：把 `kp_v` 当成普通的负反馈增益取了正值，忽略了非最小相位特性。
**代价**：数天。
**教训**：**欠驱动系统的外环符号必须推导，不能靠直觉。**
推荐两条路交叉验证：物理过程推演 + 特征方程系数判稳。

### 6.2 工具选错（`kd_wheel`）

```python
wheel_damping = -kd_wheel * self.wheel_velocity   # 看起来很合理的"轮速阻尼"
```

**表现**：加了没用，加大了更糟。
**根因**：这是直接刹车，会让车身更前倾，与平衡环正面对抗。
**教训**：**在欠驱动系统里，不能对被控量直接施加阻尼，必须经由内环。**
`kd_wheel` 这个参数本身就是个设计错误。

### 6.3 外环带宽过高（`velocity_filter_alpha`）

**表现**：外环与内环互相打架。
**根因**：一阶低通 `fc ≈ α·fs/(2π)`。α=0.3 @ 100Hz → 4.8 Hz，比内环还快。
**教训**：**串级控制中外环带宽应为内环的 1/5 ~ 1/10。**
换硬件/改采样率后，同一个 α 值对应的截止频率会变——
本项目 IMU 从 303 Hz 变成 147 Hz 后，所有滤波系数的实际含义都变了一半。

### 6.4 统计陷阱（静摩擦阈值）

**表现**：第一次测得突破电压 10~20 PWM，据此判断"静摩擦不是问题"，结论完全错误。
**根因**：样本混入了 PWM 正在爬升的瞬态。
**教训**：见 4.5 节。**测阈值必须排除瞬态样本。**

### 6.5 共模 vs 差模（摩擦补偿）

**表现**：静摩擦补偿"生效了"（高 PWM 区移动率 92.9%→97.0%）却让整体变糟，偏航暴涨。
**根因**：

```
补偿加在共模 u 上  →  left = (u + 助力) - sync
                      right = (u + 助力) + sync
```

左右轮突破电压不同。**没有助力时两轮倾向于一起卡住（对称，无偏航）**；
加了助力后被抬进"一个挣脱一个还卡着"的区间，产生大差速。
而偏航环无力纠正——它自己那点差速修正量同样推不动一个卡住的轮子。

**教训**：**摩擦补偿必须作用在差速拆分之后的每个轮子上，不能加在共模上。**
代码里现有的 `deadband_dither_hz` 通路有同样的结构缺陷。

### 6.6 硬件故障伪装成调参问题 —— 最容易浪费时间的一个

**表现**：A7 改了参数变差 → 判断是参数的锅 → A8 回退 → **没恢复，反而更差**。
**根因**：一个松动的紧固件。它同时造成零点漂移、左右不对称、整体失效。
**当时的错误**：把 A7 的退步归因于刚改的摩擦补偿。那个归因是错的——
撤销后偏航仍在，说明真凶另有其人，A7 的退步很可能也是硬件。

**判据（写死记住）**：

> **多个互不相关的指标同时退步，且回退参数无法恢复 → 停止调参，去查硬件。
> 不要归因于最近一次参数改动。**

三个典型信号：
1. 零点（平衡时平均 pitch）整体漂移
2. 出现新的左右不对称（turnAvg 突然有偏置）
3. 退步幅度远超参数改动能解释的量级

**预防**：紧固件上螺纹胶；每次长时间摔打测试后检查一遍；
把"平衡时平均 pitch"作为常规健康指标监控，它是最早的预警信号。

---

## 7. 遗留问题与后续思路

### 7.1 静摩擦补偿未实现（中等优先级）

**现状**：负载下突破电压 65~80 PWM，而控制器大部分时间工作在 25~55 PWM 区间，
即"一半概率推不动"的区域。硬件紧固后 stick-slip 大幅缓解（velMax 606→239），
但机理仍在。

**思路 A（推荐）：把补偿移到差速拆分之后**

在 `serial_bridge` 里、或在控制器中先算出左右轮 PWM 再分别补偿：

```python
left_raw  = u - sync
right_raw = u + sync
left_pwm  = left_raw  + copysign(deadband_left,  left_raw)  * scale(left_raw)
right_pwm = right_raw + copysign(deadband_right, right_raw) * scale(right_raw)
```

这样每个轮子按自己的突破电压补偿，不会互相干扰产生偏航。
`deadband_left/right` 需要**分别标定**（用 `breakaway.py` 分左右轮统计，
需要先把 `/wheel/encoders` 的左右分量单独存下来）。

**思路 B：抖动注入（dither）**

代码里已有 `deadband_dither_hz` 的 sigma-delta 实现——用满幅脉冲的占空比
去等效小扭矩，避免持续偏置。但它同样加在共模上，**必须先按思路 A 移到差模之后**。

**思路 C：硬件层面**

换更好的减速箱 / 加润滑 / 换轮胎材质。静摩擦本质是机械问题，
控制补偿只是治标。

### 7.2 `velocity_integral` 限幅是硬编码（低优先级，容易改）

```python
self.velocity_integral = max(-500.0, min(500.0, self.velocity_integral))
```

±500 ticks ≈ 1.8 圈。这个值在 A5 阶段是真实的性能瓶颈（限幅占 7.3%）。
应该提成 ROS 参数，比如 `max_velocity_integral`，方便按场地大小调整。

### 7.3 偏航只有 P 控制（低优先级）

`wheel_sync_kp` 是纯比例，能压掉系统性偏置（turnAvg +78 → +1），
但残余瞬时摆动仍有峰值 200~600。若要更严格的航向保持，可以：

- 加偏航积分项，或
- 引入 IMU 的 yaw 角做绝对航向反馈（现在只用了差模轮速，是相对量，
  会随时间累积航向漂移——**车能不转圈，但长期朝向会慢慢偏**）

### 7.4 `pitch_rate` 用差分而非陀螺仪原始值（中等优先级）

```python
pitch_rate = (pitch - self.last_pitch) / pitch_dt
```

D 项的角速度是对 pitch 做差分得到的，**差分会放大噪声**，所以才需要
`pitch_rate_filter_alpha` 低通，而低通又引入相位滞后。

IMU 本身就输出 `angular_velocity.y`（陀螺仪原始角速度），信噪比高得多。
当初改用差分是为了规避"IMU 安装轴与 Euler 轴不一致"的问题
（见代码注释）。正确做法是**做一次轴对齐标定**，然后直接用陀螺仪值，
可以同时降噪声和降滞后，为提高 kd 腾出空间。

> **⚠️ 2026-07-27 更正：以上这段在本机上被实测推翻，不要照做。**
>
> 轴对齐标定已用离线数据完成：`angular_velocity.y` 确实对应 pitch 且符号为正
> （r = +0.835，另两轴 |r| < 0.07）。**但陀螺那一路是滞后的** ——
> 互相关显示四元数推出的 pitch 角速度**超前陀螺 18 ms**
> （谱分析在 6~9 Hz 给出 +50.6 度，两法吻合）。
> 换用陀螺会在 7~9 Hz 自激点上再叠 50 度相位滞后，只会更糟。
> 详见 `docs/07_遥控与录制_2026-07-26.md` 第 11 节 ③。

### 7.5 IMU 采样率异常下降（待查）

文档 04 记录 IMU 为 303 Hz，本次实测为 **147~152 Hz**，掉了一半，原因不明。
可能是驱动配置、USB 带宽或 IMU 内部输出速率设置。

**影响**：所有一阶滤波系数的实际截止频率都减半了
（`fc ≈ α·fs/(2π)`）。当前参数是在 147 Hz 下调的，
如果哪天 IMU 恢复到 303 Hz，`pitch_rate_filter_alpha` 和
`velocity_filter_alpha` 需要相应减半才能保持等效。

### 7.6 尚未实现运动控制（下一阶段的主要工作）

现在外环的速度目标隐含为 0，只会原地站立。要让它能走：

```python
# 现在
offset_trim = kp_v * self.wheel_velocity + ki_v * self.velocity_integral

# 改成
vel_err = self.wheel_velocity - target_velocity
offset_trim = kp_v * vel_err + ki_v * self.velocity_integral
# 注意：给了非零速度目标后，位置积分的含义变成"相对于期望轨迹的位置误差"，
# 需要同步处理，否则积分会持续累积
```

转向类似：给偏航环一个 `target_turn_velocity` 而不是恒定 0。

再往上才是导航层（里程计、路径跟踪）。注意目前 `ticks_per_rev = 277.5`
是手转粗标的，做里程计前需要精标定。

### 7.7 安全性

- ✅ Arduino 固件已有指令看门狗（`CMD_TIMEOUT_MS`），串口断开会自动清零 PWM
- ✅ 轮速安全锁存 `max_wheel_velocity`
- ✅ 倾角超限切断 `max_tilt_deg`
- ⚠️ `latch_on_fall` 调试期设为 `false`，**无人值守运行前务必改回 `true`**，
  否则一次摔倒后会反复自动上电
- ⚠️ 无电池电压监控。电压下降会改变电机增益，进而改变所有等效增益，
  建议增加电压话题并在低压时告警

---

## 8. 面试准备

### 8.1 一句话项目描述

> 基于 ROS2 的两轮自平衡机器人，采用角度环 / 速度环 / 位置环 / 偏航环的四环串级 PID 控制，
> 通过 rosbag 数据驱动的方式完成参数整定，实现单次连续平衡超过 228 秒，
> 车身角度控制在 ±1° 以内，原地位置保持在 1/4 轮周以内。

### 8.2 高频问题与答法

**Q：为什么要用串级控制？只调一个角度 PID 不行吗？**

A：不行，而且我有实测数据。只有角度环时，车身确实能稳定在 ±2.5° 以内，
但整车会以 430 ticks/s 持续加速跑掉。原因是角度环的目标只是"让 pitch 等于设定值"，
只要设定值有微小偏差，车身就会稳定保持一个微小倾角，而持续倾斜的平衡车会持续加速，
角度环对此毫无察觉——它的误差是零。这是欠驱动系统的本质：
一个执行器要控制两个自由度，必须用串级结构分层处理。

**Q：平衡车的速度环增益为什么是负的？**

A：因为它是非最小相位系统。要让前进的车减速，不能直接刹车——
那样车身会因惯性更加前倾，角度环会立刻加大前进油门去救它，刹车动作被完全抵消。
正确做法是先加大前进油门，把轮子送到重心前面，车身被"抽"得后仰，
然后角度环为了追这个后仰的重心，自己会输出反向 PWM 完成减速。
符号可以严格推导：v>0 要减速 → 需要 u 更正 → err 更正 → 目标角更小 →
trim 为负 → kp_v 为负。也可以从特征方程 `s² - K'·kp_v·s - K'·ki_v = 0`
的系数判稳得到同样结论。这个符号我们项目早期搞反了，导致速度环是正反馈，
浪费了好几天。

**Q：你是怎么调参的？试凑吗？**

A：不是，是数据驱动。流程是：`ros2 param set` 设参数 → `ros2 bag record` 录包
→ 拉回本地离线分析 → 从指标推下一组参数。
关键在于离线分析时**精确复现控制器的状态机**——因为知道全部参数，
可以重建每一段"接管"的起止和退出原因。这个"退出原因"这一列价值极高：
如果全是倾角超限，说明角度环兜不住；如果全是轮速超限，说明角度环没问题，
是速度失控。我们第一轮的数据是 29 段全部轮速超限、0 次倾角超限，
直接就把排查方向从角度环转到了速度环，避免了继续在错误的地方调 kp/kd。

**Q：举一个你用理论指导调参的例子。**

A：位置环出现了 8.8 秒周期的来回摆。我先判断这是不是线性欠阻尼：
由观测周期反推 ω_n ≈ 0.785 rad/s，再由 `ω_n² = -K'·ki_v` 反推系统增益 K' ≈ 411，
最后算出阻尼比 ζ ≈ 1.31。**过阻尼系统不会振荡**，所以这个摆动不是 PID 参数问题，
另有原因（后来查出是积分限幅）；同时也说明阻尼有富余，可以拿来换刚度。
于是把 ki_v 加倍、kp_v 小幅跟进，预测周期降到约 6.2 秒——
实测 5.16 秒，位置摆幅从 3.6 圈降到 1.4 圈。用理论先做定量预测再验证，
比盲目试参数效率高一个数量级。

**Q：机械零点是怎么标定的？**

A：一开始是静态标定——扶正了采样取平均，但这个方法很脆弱，
人手扶的姿态和真实平衡点未必一致，之前为此反复扫描浪费了大量时间。
后来我用了一个更好的方法：**当车在自主平衡、且长时间平均轮速为零时，
车身的平均 pitch 就是真实机械平衡点**。因为平均轮速为零意味着长期没有净加速度，
车身平均姿态必然就是重力力矩为零的姿态。
两轮独立数据给出 7.528° 和 7.554°，一致到 0.03°。
更重要的是这个方法**自带验证判据**：零点对了以后，速度环积分的均值应该趋近于零、
且不再撞限幅——实测从 -322 降到 -49，限幅占比从 8.5% 降到 0%。

**Q：讲一个你调试中判断失误的例子。**

A：有一轮我加了静摩擦补偿，结果所有指标都变差、偏航特别严重，
我第一反应是补偿的锅，就把它撤销了。**结果撤销后没恢复，反而更差。**
这说明我的归因是错的。回头看三个信号：平衡时的平均 pitch 整体漂移了 0.5°、
突然出现左右不对称、退步幅度远超参数改动能解释的量级——
这三条同时出现只能是机械问题，最后查出是紧固件松动。
这件事给我的教训是：**当多个互不相关的指标同时退步、
且回退参数无法恢复时，应该立刻停止调参去查硬件，而不是归因于最近一次改动。**
后来我把这条写进了项目文档作为判据。

**Q：还有什么没做好的？**

A：主要三点。第一，静摩擦补偿还没做对——现在的实现加在共模上，
会导致一个轮子挣脱另一个还卡着，产生偏航，正确做法是移到差速拆分之后按轮补偿。
第二，D 项的角速度是对 pitch 做差分得到的，噪声大、需要低通、又引入滞后；
应该做一次轴对齐标定后直接用陀螺仪原始角速度。
第三，偏航只有比例控制，用的是编码器差模这个相对量，
长期朝向会缓慢漂移，需要引入 IMU 的 yaw 做绝对反馈。

### 8.3 值得强调的能力点

| 能力 | 本项目中的体现 |
|---|---|
| 控制理论落地 | 串级结构设计、非最小相位符号推导、二阶系统阻尼比定量分析 |
| 数据驱动调试 | 离线复现状态机、按失败模式分类、自制 4 个诊断脚本 |
| 系统性排障 | 从"退出原因"分布直接定位子系统，避免在错误的环上耗时 |
| 工程严谨性 | 识别统计陷阱、区分硬件故障与参数问题、参数固化与复现验证 |
| 复盘意识 | 把错误结论和判据写进文档，包括自己犯过的归因错误 |

---

## 附：相关文件索引

| 文件 | 内容 |
|---|---|
| `config/balance_params.yaml` | 最终参数（带推导注释） |
| `launch/balance.launch.py` | 一键启动 |
| `balance_bot/balance_controller.py` | 控制器实现 |
| `docs/05_balance_achieved_2026-07-25.md` | 英文版结果记录与参数推导 |
| `docs/04_balance_tuning_pause_2026-07-24.md` | 本次调参前的状态 |
| `results/rosbag/tuneA1` ~ `tuneA11_fromfile` | 全部原始数据 |

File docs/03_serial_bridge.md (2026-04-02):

# Stage 3: ROS2 Serial Bridge Node

> Date: 2026-04-02
> Environment: Raspberry Pi 5 + Ubuntu 24.04 + ROS2 Jazzy + Arduino Mega 2560

## Result

- `serial_bridge` node running, `/cmd_vel` controls motors via serial
- `/wheel/encoders` topic publishing encoder data at ~100Hz
- Keyboard teleoperation working — instant response
- `bringup.launch.py` launches IMU + serial_bridge with one command

---

## Architecture

```
teleop_twist_keyboard
        ↓ /cmd_vel (geometry_msgs/Twist)
  serial_bridge node
        ↓ "M,left_pwm,right_pwm\n"  (USB serial, 115200 baud)
    Arduino Mega
        ↓ PWM
      TB6612FNG → MG310P20 motors

    Arduino Mega
        ↑ "E,left_count,right_count\n"  (every 10 ms)
  serial_bridge node
        ↑ /wheel/encoders (std_msgs/String)
```

---

## Node: serial_bridge

**File:** `src/balance_bot/balance_bot/serial_bridge.py`

**Subscriptions:**
- `/cmd_vel` (geometry_msgs/Twist) — velocity command input

**Publications:**
- `/wheel/encoders` (std_msgs/String) — encoder counts, format `"left,right"`

**Key logic:**

```python
# cmd_vel → PWM conversion
left_pwm  = int((linear.x - angular.z) * 100)
right_pwm = int((linear.x + angular.z) * 100)

# Serial read thread — runs independently to avoid blocking rclpy.spin()
threading.Thread(target=self._read_serial, daemon=True).start()
```

---

## Launch File

**File:** `src/balance_bot/launch/bringup.launch.py`

```bash
ros2 launch balance_bot bringup.launch.py
```

Starts both nodes simultaneously:
- `hfi_imu` → publishes `/imu/data`
- `serial_bridge` → publishes `/wheel/encoders`, listens on `/cmd_vel`

---

## Issues & Fixes

**1. `pip3 install pyserial` blocked by system package manager**

Debian 12+ protects the system Python environment. Fix:
```bash
sudo apt install python3-serial
```

**2. TabError: inconsistent use of tabs and spaces**

nano mixed tabs and spaces when pasting code. Fix: rewrite the file entirely using only spaces (4-space indent throughout).

**3. ROS2 topic discovery latency (~2 minutes on first publish)**

Symptom: `ros2 topic pub --once` command returns immediately but motor takes minutes to respond.

Root cause: FastDDS multicast discovery is slow on Raspberry Pi with multiple network interfaces. Tried `ROS_LOCALHOST_ONLY=1`, CycloneDDS with `lo` interface, static peers — none fully resolved the issue on this setup.

Workaround: Use `-r 10` (continuous publish at 10 Hz) instead of `--once`. Once connection is established, response is instant. In practice this is not an issue because `teleop_twist_keyboard` maintains a persistent connection.

---

## Lessons Learned

| # | Lesson |
|---|---|
| 1 | Serial read must run in a dedicated thread — `readline()` blocks, cannot run inside `rclpy.spin()` |
| 2 | Use `sudo apt install python3-serial` on Debian-based systems, not `pip3 install pyserial` |
| 3 | `ros2 topic pub --once` is unreliable for testing when DDS discovery is slow; use `-r 10` instead |
| 4 | `/cmd_vel` (geometry_msgs/Twist) is the standard ROS2 velocity interface — always prefer it over custom topics for motion commands |
| 5 | `data_files` in `setup.py` must explicitly include the `launch/` directory, and requires `import os` + `from glob import glob` |

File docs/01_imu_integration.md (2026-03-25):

# Week 1 Troubleshooting: HFI-A9 IMU Integration

> Date: 2026-03-24
> Environment: Raspberry Pi 5 + Ubuntu 24.04 + ROS2 Jazzy

---

## Final Result

- HFI-A9 IMU successfully integrated, `/imu/data` topic publishing at ~**295Hz**
- `imu_reader` node running, Pitch angle changes in real time when IMU is tilted
- All Week 1 requirements completed

---

## Issue 1: `ros2 --version` error

**Symptom:** `ros2 --version` reports `unrecognized arguments`

**Cause:** ROS2 CLI does not support the `--version` flag

**Fix:**
```bash
printenv ROS_DISTRO   # correct way to check ROS2 version
```

---

## Issue 2: `cp` command caused nested directory mess

**Symptom:** Copying driver package from `products` repo into `src/` while already inside `src/` created a `src/src/` nested structure; colcon reported duplicate package error

**Cause:** `cp` executed inside `src/`, with `products` repo also inside `src/`, causing recursive path collision

**Fix:**
```bash
cd ~/ros2_ws/src
rm -rf products src   # delete products repo and the mistaken src/src/
# keep only hipnuc_imu and hipnuc_lib_package
```

---

## Issue 3: System bzip2 dependency conflict, cannot install build-essential

**Symptom:**
```
libbz2-dev: Depends: libbz2-1.0 (= 1.0.8-5.1) but 1.0.8-5.1build0.1 is to be installed
```

**Cause:** Installed `libbz2-1.0` is the arm64 rebuild version (`build0.1` suffix), exact version mismatch with `bzip2` requirement

**Fix:**
```bash
sudo apt install libbz2-1.0=1.0.8-5.1 --allow-downgrades
sudo apt install build-essential -y
```

---

## Issue 4: hipnuc driver switches all default to FALSE, no data published

**Symptom:** After launch, `ros2 topic hz /IMU_data` shows "does not appear to be published yet"

**Cause:** Three switches in `hipnuc_config.yaml` default to `FALSE`:
```yaml
imu_switch: FALSE
euler_switch: FALSE
magnetic_switch: FALSE
```

**Fix:**
```bash
sed -i 's/: FALSE/: TRUE/g' ~/ros2_ws/src/hipnuc_imu/config/hipnuc_config.yaml
colcon build --packages-select hipnuc_imu
```

---

## Issue 5: Internal QoS incompatibility warnings

**Symptom:** launch logs continuously show `RELIABILITY_QOS_POLICY` incompatibility warnings

**Cause:** hipnuc package's internal publisher uses `BEST_EFFORT`, built-in listener uses `RELIABLE`

**Impact:** Does not affect external subscribers — can be ignored. Add `--qos-reliability best_effort` when subscribing externally

---

## Issue 6: No data even after enabling switches (root cause)

**Symptom:** `ros2 topic echo --qos-reliability best_effort /IMU_data` produces no output

**Investigation:**
1. Read source `serial_port.cpp` — sync header is `0x5A 0xA5`
2. Used Python to read raw serial data — no `5A A5` found in 500 bytes
3. Tried different baud rates (9600, 115200, 460800) — still no `5A A5`

**Root causes (two):**
1. **Wrong driver entirely:** hipnuc driver sync header is `5A A5`, but HFI-A9 actual protocol sync header is `AA 55`
2. **Wrong baud rate:** config says 115200, HFI-A9 actual default baud rate is **921600**

**Conclusion:** HFI-A9 is a HandsFree/TaoBotic product, not a genuine HiPNUC device — hipnuc driver is completely incompatible

---

## Issue 7: Official driver is ROS1, cannot be used with ROS2

**Symptom:** `handsfree_ros_imu` repo is a ROS1 catkin package using `rospy`, cannot compile under ROS2 Jazzy

**Fix:** Referenced the protocol parsing logic from the official ROS1 script `hfi_a9_ros.py` and wrote a ROS2 Python node from scratch

Key protocol parameters (reverse-engineered from ROS1 source):
- Sync header: `0xAA 0x55`
- Baud rate: 921600
- Packet type `0x2C` (44 bytes): gyro + accelerometer + magnetometer raw data
- Packet type `0x14` (20 bytes): Roll/Pitch/Yaw Euler angles
- Checksum: CRC16

---

## Final Solution

**File:** `src/balance_bot/balance_bot/hfi_imu_node.py` (standalone ROS2 Python node)

**How to run:**
```bash
# Terminal 1: start IMU node
source ~/ros2_ws/install/setup.bash
python3 ~/ros2_ws/src/balance_bot/balance_bot/hfi_imu_node.py

# Terminal 2: run imu_reader
source ~/ros2_ws/install/setup.bash
ros2 run balance_bot imu_reader
```

**Verified results:**
- Topic: `/imu/data` (sensor_msgs/Imu)
- Frequency: ~295Hz
- Data: quaternion, angular velocity, linear acceleration all normal

---

## Issue 8: PC (VM) cannot discover ROS2 topics from Raspberry Pi

**Symptom:** Node running normally on Pi, `ros2 topic list` visible on Pi itself, but completely invisible from PC VM

**Investigation:**
1. ping succeeds → basic network is fine
2. domain ID matches (both default 0) → not a domain ID issue
3. Setting `CYCLONEDDS_URI` had no effect → because default RMW is FastDDS, not CycloneDDS

**Root cause:** VM network adapters typically do not forward DDS multicast packets; FastDDS relies on multicast for node discovery by default

**Fix:** Switch both sides to CycloneDDS and specify peer IP for unicast discovery

```bash
# Install and switch RMW on both machines
sudo apt install ros-jazzy-rmw-cyclonedds-cpp -y
export RMW_IMPLEMENTATION=rmw_cyclonedds_cpp

# On Pi (pointing to PC IP)
export CYCLONEDDS_URI='<CycloneDDS><Domain><Discovery><Peers><Peer address="192.168.1.1"/></Peers></Discovery></Domain></CycloneDDS>'

# On PC (pointing to Pi IP)
export CYCLONEDDS_URI='<CycloneDDS><Domain><Discovery><Peers><Peer address="192.168.1.16"/></Peers></Discovery></Domain></CycloneDDS>'
```

**Note:** Must re-export in every new terminal. Add to `~/.bashrc` for permanent effect.

---

## Lessons Learned

| # | Lesson |
| - | --- |
| 1 | Always verify manufacturer and protocol before using a driver — never assume compatibility |
| 2 | `ros2 topic list` showing a topic ≠ topic has data — always verify with `hz` and `echo` |
| 3 | When official driver is ROS1, read the protocol parsing logic and write your own ROS2 version |
| 4 | Resolve system package dependency conflicts with `--allow-downgrades` |
| 5 | For serial debugging, use `xxd` to inspect raw bytes first — confirm sync header and baud rate |
| 6 | For ROS2 cross-machine comms in VM: switch to CycloneDDS + manually specify peer IP |

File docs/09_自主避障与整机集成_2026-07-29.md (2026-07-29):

# MVP2 后半段：从"能停"到"能自己走"，再到"开机就能用"

> 2026-07-29。前置：`docs/08_MVP2深度相机接入_2026-07-28.md`（感知链路打通）。
>
> 这一篇的每一个改动都由一次失败驱动，而且**大部分失败的根因不是参数，是几何、
> 是状态机的边界、或者是我自己造出来的死区**。

---

## 1. 起点：一句正确的批评

08 篇结束时，护栏能在障碍前停下，四个状态都验证过。但用户的评价是：

> "我现在是手柄控制，感觉避障的意义不是很大"

**这个判断是对的。** 手动驾驶下，一个只会"看到障碍就停"的护栏近乎无用 ——
人的眼睛比相机好，会比它更早停。

护栏的价值不在阻止人犯错，而在**给一个看不见的指令源当底座**。
所以缺的是最上面那一层：让车自己开。

架构上不需要改动，因为护栏从一开始就设计成"只削减不产生"：

```
explorer（自主）──┐
                  ├──► guard ──► balance_controller
手柄（人工）  ────┘   （安全层，始终在）
```

**上层决定去哪，可以犯错；下层决定什么能活下来，不可以。**
自主逻辑写错了应该表现为乱转，而不是撞车。

---

## 2. "离得很远就呆住"：判定区域的形状错了

第一版自主跑起来后，车在**离障碍还很远时就停下转圈**。
直觉会归因为"阈值太保守"，改参数就行。**但根因是几何。**

我把"车要走的通道"定义成**固定角度的扇形**（±0.30 rad），而车是**固定宽度**的
（轮距 0.22 m）。扇形随距离张开：

| 距离 | 扇形通道宽度 | 车实际需要 | 倍数 |
| --- | --- | --- | --- |
| 1.0 m | 0.62 m | 0.22 m | 2.8× |
| 2.0 m | 1.24 m | 0.22 m | 5.6× |
| 3.0 m | 1.86 m | 0.22 m | 8.4× |

**在 2 米处，偏在旁边 0.6 米的东西会被判成挡路** —— 车根本撞不到它。

改成按**横向偏移**判定（`r·sin θ`，米，不是角度）。
改完最有说服力的一行数据：`near=1.87` 时护栏报 `CLEAR 1.86` ——
**两个数几乎相等**，说明通道量的是真正会挡路的东西。

> 一个诚实的说明：我拿单帧数据去验证时**没能证明差别**（三种通道最近距离都是
> 0.75 m），因为那帧障碍横跨整个视野。几何论证成立，但**证据要在真车上取**，
> 不能拿一个不区分的用例当通过。

---

## 3. 从"挡住就停"到"找缝隙钻过去"

二元的"挡住/没挡住"会让车停在一个它本可以直接开过去的门口。

改成 **follow-the-gap**：逐方位判断"车走这边能不能过"，把连续可通行的方位分组，
**选最宽的、够车过的那一组，朝它中心走**。

缝隙宽度按**米**算而不是按方位数 —— 同样几个方位在 1 米和 3 米处是完全不同的
物理宽度，一个 1 米处明显够宽的门在 3 米处只占几个方位，看起来像噪声。

**上真车前先单元测**：

```
0.5 m 门洞在正前方  →  朝 +0 度走   宽 0.50 m
0.4 m 门洞          →  朝 +0 度走   宽 0.42 m
0.2 m 太窄          →  拒绝         宽 0.18 m
0.5 m 缺口在左边    →  朝 +19 度走  宽 0.46 m
两个缺口，左边更宽  →  朝 +17 度走
```

实车效果：**前进速度全程保持 0.10，只叠加转向**。

```
gap=+0deg/1.16  →  +0.10/+0.00     缝隙在正前方，直行穿过
gap=+5deg/0.50  →  +0.10/+0.10     偏左，边走边带
gap=-13deg/0.6  →  +0.10/-0.26     偏得多，转得多
```

有一段它靠这个从 1.18 m 一路带回 2.28 m 开阔处，**全程没进 TURN 状态**。
**用转向避障不损失前进；用停车避障把整段接近都浪费掉了。**

---

## 4. 撞上桌腿：三个问题叠加，没有一个是"看不见"

改完之后车撞了桌腿。**日志显示扫描全程看得见它**（0.86~0.88 m，稳定三秒）。

### ① 我自己造出了一个死区

护栏 1.20 m 开始减速，0.87 m 时已削到 **0.045 m/s**；
而 explorer 的转向触发是 **0.85 m** —— 永远够不到。

**在这两个数之间，谁都不负责转弯。** 两个模块各自合理，边界重叠处出了洞。

修法不是挪阈值，是换判据：**`gap=none` 本身就是转向的理由**，与距离无关。
"走不过去"才是值得反应的事，等到近了再看，白白浪费了转向最廉价的那段距离。

### ② 减速削出了车走不动的速度

0.045 m/s 低于静摩擦突破电压，**轮子根本不转**。
距离读数三秒不变（0.86→0.88）就是铁证 —— 车没动，只是前倾顶着，
平衡环在 ±120 PWM 之间挣扎，最后倒在桌腿上。

**这是 `docs/07` 记录过的静摩擦死锁，从一条新路径回来了：是护栏自己生成的。**

修法：前进指令要么给到能走动的下限（0.07 m/s），要么给零，
不产生中间那段"命令了但动不了"的速度。

### ③ 缝隙方位没滤波

0.6 秒内跳 `+18 → +13 → +2 → -14 → +16 → 0` 度，转向指令直接跟着抖，
平衡输出在 +255 / −105 之间饱和。根源是 44% 的方位是未知的，
`passable` 判定逐帧闪烁，最宽缝隙在几个候选间反复横跳。

加一阶平滑即可。**给了搜索能力就必须给稳定性，否则搜索结果本身成了噪声源。**

---

## 5. 卡在死角转不出来：等待条件不会终止

修完上面三条后，车在窄处会**扫一圈 → 后退 12 cm → 再扫一圈**，无限循环。

根因：`TURN` 的退出条件是"某个方向距离超过阈值"，
而**窄地方所有方向都不超**。

> **等一个足够好的，在没有足够好的时候不会终止。
> 从看到的里面挑最好的，一定终止。**

改成：用 IMU 航向量扫过的角度（不是计时器），**边扫边记住哪个方向最空，
扫满一圈就朝那个方向去**。后退保留为兜底 —— 当连"最好的"也不行时，
解法是换个位置。

实测从 0.47 m 的死角转出到 1.90 m 开阔处，没停、没撞、平衡没断。

---

## 6. 双模式：自主与手动的仲裁

`cmd_mux` 独占 `/cmd_vel_raw`，在 explorer 和手柄之间选择。

**判据是"有没有指令流"，不是"手柄开没开机"** ——
`teleop_twist_joy` 只在死人开关按住时才发消息，
所以**一条手动消息到达本身就意味着有人握着**，不需要再推断什么。

**抢夺立即，交还延迟 0.5 秒**，这个不对称是刻意的：
人抢控制权通常是因为车要干蠢事，不能等；
而消息流里一个短暂空隙不代表撒手了。

好处是手柄可以一直开着待命，不影响车自己跑。

---

## 7. 开机自启：把一堆节点变成一台能用的机器

`systemd` 单元 + 启动脚本，一次通电起全套：相机 → 平衡 → 感知 → 仲裁 →
护栏 → 自主 → 手柄 → 录制。

几个不是装饰的细节：

**顺序靠等待保证，不靠祈祷。** USB 枚举比 systemd 慢，脚本轮询设备节点存在。

**防重入。** 手动跑一次和 `systemctl start` 撞在一起，产生了**每个节点 3 份**、
143 条串口错误 —— 这里每个节点都独占一个设备，**第二份不会大声失败**，
只会安静地互相干扰。脚本现在先杀同名节点再启动。

**日志按启动归档**（`~/robot_logs/boot_<时间戳>.log`），保留最近 20 次，自动轮换。

**录制刻意不含 `/depth/image`** —— 它约 29 MB/s，我加进去一次，
**六分钟写掉了 SD 卡的五分之一**（9.2 GB）。重建"车当时如何决策"所需的一切
都在扫描和指令话题里。

---

## 8. 最有价值的一个 bug：冻住的传感器骗过了接管判据

重启验证时，用户报告"**接管时还没平衡**"。

查下去：IMU 的 USB 适配器**重新枚举**了，回来时变成 `ttyUSB1`，
而节点还握着 `ttyUSB0` 的文件描述符。它的异常处理只打日志然后返回，
于是**在一个死掉的句柄上无限刷 `Errno 5`**，永不恢复。

两个串口节点现在都会关闭死 fd 并走 `by-id` 路径重开
（`by-id` 跟着设备走，`ttyUSB` 编号不跟）。

### 但更严重的问题在下游

**控制器无法从数值本身分辨"姿态稳定"和"数据停止更新"。**

冻住的读数呈现为**误差恒定、角速度为零** —— 而那**正是接管的条件**。
于是它在车根本没平衡的姿态下接管了。

判据最后很简单：**活着的 IMU 从不连续两帧给出完全相同的浮点数**，
噪声保证了这一点。

在 **24.5 万帧真实数据里，最长的"逐位相同"连续段是 1 帧**。
阈值取 40 帧（约 0.28 s），**40 倍余量，不可能误触发**。

另加一个独立定时器：0.25 秒收不到 IMU 就**显式脱离**。
之前是回调不触发、节点整个停摆，靠 `serial_bridge` 的看门狗兜底 ——
电机确实会停，但**控制器自己以为还在接管**，
下一帧陈旧数据到达就会从一个没人检查过的状态恢复控制。

> **这个 bug 只有重启才能暴露，看代码想不出来。**
> 也是整个项目里最值得记的一条：
> **一个传感器失效时"看起来正常"，比它明显报错危险得多。**

---

## 9. 遗留

**① 视野 58°，转过去之前看不到那边。** 逃离封闭空间是搜索而不是规划。
根治要么换更宽的传感器，要么**记住刚才看到的**（局部占据栅格）。

**② 悬空障碍。** 障碍高度带是 3~50 cm，桌面（70 cm）被当作"从头顶过去"忽略。
车比 50 cm 矮所以撞不到桌面，但这个假设是隐式的，换个更高的底盘就不成立。

**③ 后退无防护。** 相机朝前，`BACKUP` 时背后完全看不见。

**④ `latch_on_fall` 仍为 `false`** —— 摔了自动重新接管。
有人看着时方便，无人值守时会变成"摔倒→爬起→再摔"。

**⑤ 沿用前几篇的遗留**：静摩擦死锁（前进偶发卡死）、
系统级偶发停摆（约 1/30 万）、IMU 零偏温漂。

---

## 10. 文件索引

| 文件 | 作用 |
| --- | --- |
| `balance_bot/explorer.py` | 自主漫游：找缝隙、扫描-提交、脱困 |
| `balance_bot/avoidance_guard.py` | 安全层：矩形通道、减速下限、失效即停 |
| `balance_bot/cmd_mux.py` | 自主/手动仲裁 |
| `launch/autonomy.launch.py` | 感知+仲裁+护栏+自主+手柄，一条命令 |
| `scripts/start_robot.sh` | 开机启动脚本（顺序、防重入、日志轮换） |
| `scripts/balance-bot.service` | systemd 单元 |

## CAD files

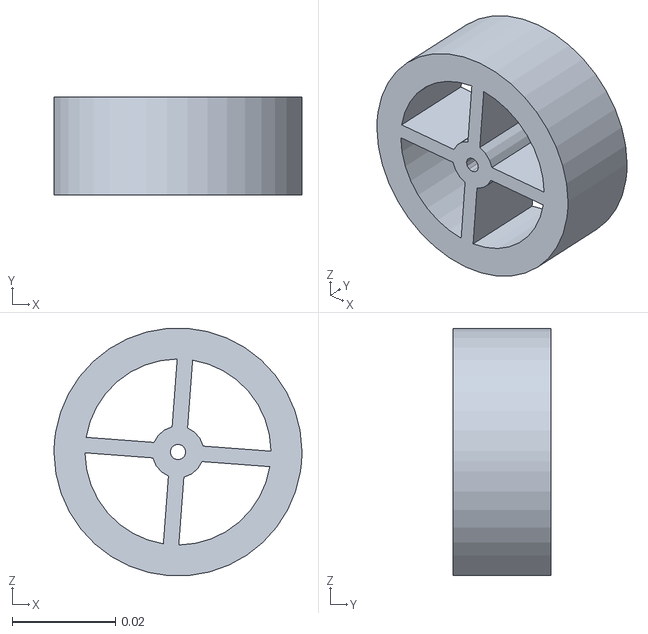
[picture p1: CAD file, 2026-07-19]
src/balance_bot_description/meshes/right_wheel.STL
0.048 x 0.019 x 0.0479

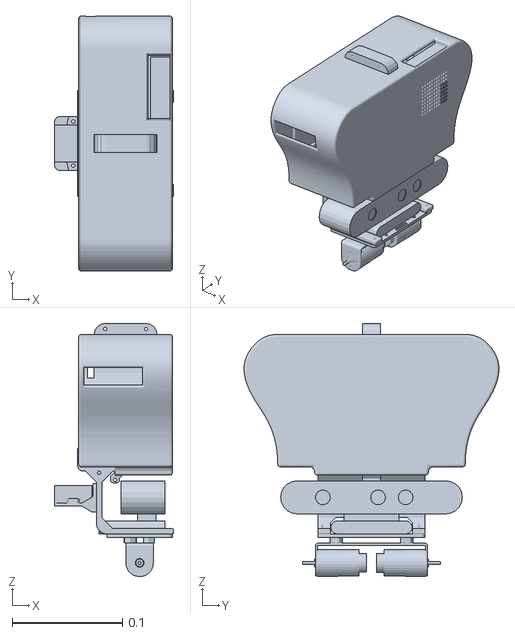
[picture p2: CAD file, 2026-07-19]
src/balance_bot_description/meshes/base_link.STL
0.108 x 0.231 x 0.23

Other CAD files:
src/balance_bot_description/meshes/left_wheel.STL

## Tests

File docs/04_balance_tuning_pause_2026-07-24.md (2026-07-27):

# Balance Tuning Pause - 2026-07-24

## Safe Pause State

- The remote `balance_controller` was stopped deliberately.
- A zero `/cmd_vel` command was sent after stopping it.
- `/hfi_imu` and `/serial_bridge` remain available on the Raspberry Pi.
- Do not resume a controller test until the robot is hand-supported near upright.

## Facts Confirmed During This Session

- IMU rate is about 303 Hz and encoder rate is about 100 Hz after the Pi reboot.
- Both motor channels and both encoder channels were verified earlier with synchronized PWM tests.
- Positive PWM moves the wheels forward. A single-direction IMU check confirmed that leaning
  the body toward its physical front raises the controller pitch value.
- Therefore `motor_output_sign:=1.0` is the correct polarity. Do not flip it as a tuning step.
- The apparent recoveries in some earlier runs were caused by external contact or hand input,
  not autonomous recovery. Treat those runs as failed balance attempts.

## Reliable Fixed Pitch Reference

The most recent deliberate upright calibration is the reference to use on resume:

```text
pitch_offset_deg = 7.20
standard deviation = 0.11 deg
samples = 2374 over 8 s
```

The earlier `12.10 deg` sample was explicitly marked inaccurate and must be discarded.
Automatic capture produced inconsistent values between roughly 5 and 13 deg, so resume with
`capture_offset_on_engage:=false` and the fixed 7.20 deg offset until a better calibration
method is implemented.

## Controller Changes Already Made

`balance_bot/balance_controller.py` now includes:

- Independent positive and negative PWM limits: `max_pwm_fwd`, `max_pwm_bwd`.
- A configurable wheel-runaway safety latch: `max_wheel_velocity`.
- Stable-pose capture parameters: `capture_settle_time_sec`, `capture_rate_below_dps`.
- Smooth static-friction and recovery parameters already exposed by the controller.

The wheel-speed latch is useful while hand-tuning because a supported body can otherwise let
the wheels run into a wall without exceeding the pitch limit.

## Latest Test and Result

The last protected test used the reliable fixed offset but was not stable:

```text
capture_offset_on_engage=false
pitch_offset_deg=7.20
kp=70, kd=5
max_pwm_fwd=255, max_pwm_bwd=255
deadband_ramp_deg=0.5
recovery_pwm=110, recovery_err_deg=0.5, recovery_ramp_deg=1.5
max_tilt_deg=5, max_wheel_velocity=250
```

It reached a filtered wheel speed of about +271 ticks/s and the wheel-speed protection cut
output. This parameter set must not be described as balanced or reused unchanged.

## Resume Plan

1. Start from the fixed 7.20 deg reference, with auto-capture disabled and the wheel-speed
   safety latch enabled.
2. Keep the smooth static-friction ramp; avoid the earlier abrupt recovery boost.
3. Tune a bounded velocity/position braking term so wheel motion is opposed before it reaches
   the safety limit, then retune pitch P/D around that behavior.
4. Keep each run hand-supported and use the safety latch as the stopping condition; do not use
   a wall or a manual push as evidence of autonomous recovery.

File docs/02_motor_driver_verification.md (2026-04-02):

# Stage 2: Motor Driver & Encoder Verification

> Date: 2026-03-26 ~ 2026-04-01
> Hardware: Raspberry Pi 5 + Arduino Mega 2560 + TB6612FNG + MG310P20 (Hall encoder)

## Result

- Dual MG310P20 motors driving correctly via TB6612FNG
- Both encoders reading stably with consistent count rates
- Direction calibrated — right motor PWM inverted due to mirrored mounting
- Serial protocol verified: Pi Python script controls motors via USB serial

---

## Wiring

### TB6612FNG → Arduino Mega

| TB6612 | Arduino | TB6612 | Arduino |
|---|---|---|---|
| PWMA | 6 | PWMB | 9 |
| AIN1 | 4 | BIN1 | 7 |
| AIN2 | 5 | BIN2 | 8 |
| STBY | 10 | VCC | 5V |
| VM | 5V (temp) | GND | GND |

### MG310P20 Connector (pins 1–6, Hall encoder version)

| Pin | Function | Left motor | Right motor |
|-----|---|---|---|
| 1 | Motor – | TB6612 AO2 | TB6612 BO2 |
| 2 | Encoder VCC | Arduino 5V | Arduino 5V |
| 3 | Encoder A | Arduino **2** | Arduino **18** |
| 4 | Encoder B | Arduino **3** | Arduino **19** |
| 5 | Encoder GND | Arduino GND | Arduino GND |
| 6 | Motor + | TB6612 AO1 | TB6612 BO1 |

> All GND rails must be common: TB6612 GND, encoder GND, and power GND all tied to Arduino GND.

---

## Serial Protocol

```
Arduino → Pi  (every 10 ms):  E,<left_count>,<right_count>\n
Pi → Arduino  (on demand):    M,<left_pwm>,<right_pwm>\n   (range: –255 ~ 255)
```

Verified output (motors stopped):
```
E,882,3641
E,882,3641
```

---

## Firmware

| File | Purpose |
|---|---|
| `step1_motor_test.ino` | Fixed PWM, verify motor spins |
| `step2_encoder_test.ino` | Single motor + encoder, print count |
| `step3_dual_motor.ino` | Dual motor + dual encoder, verify direction |
| `step4_serial_protocol.ino` | Full serial protocol — final Week 2 firmware |

---

## Issues & Fixes

**1. TB6612 STBY not wired → motors dead**
STBY floats LOW, disabling the chip. Fix: `digitalWrite(STBY, HIGH)` in `setup()`.

**2. B-side control pins not connected → right motor dead**
Forgot BIN1/BIN2/PWMB after verifying left motor. Fix: wire pins 7, 8, 9.

**3. Mirrored motors → robot spins in place**
Same PWM direction is physically opposite for left vs right. Fix: invert right motor PWM in firmware, no rewiring needed.

**4. Serial monitor line ending wrong → M command ignored**
Arduino waits for `\n` to parse commands. Fix: set line ending to **"Newline"** in Arduino IDE serial monitor.

---

## Lessons Learned

1. Always check enable pins first when a motor driver doesn't respond
2. Verify each side of a dual motor driver independently
3. Handle mirrored motor direction in firmware, not hardware
4. Confirm serial tool line-ending settings before debugging protocol issues

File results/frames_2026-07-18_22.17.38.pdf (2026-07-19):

view_frames Result

Recorded at time: 1784384258.590154

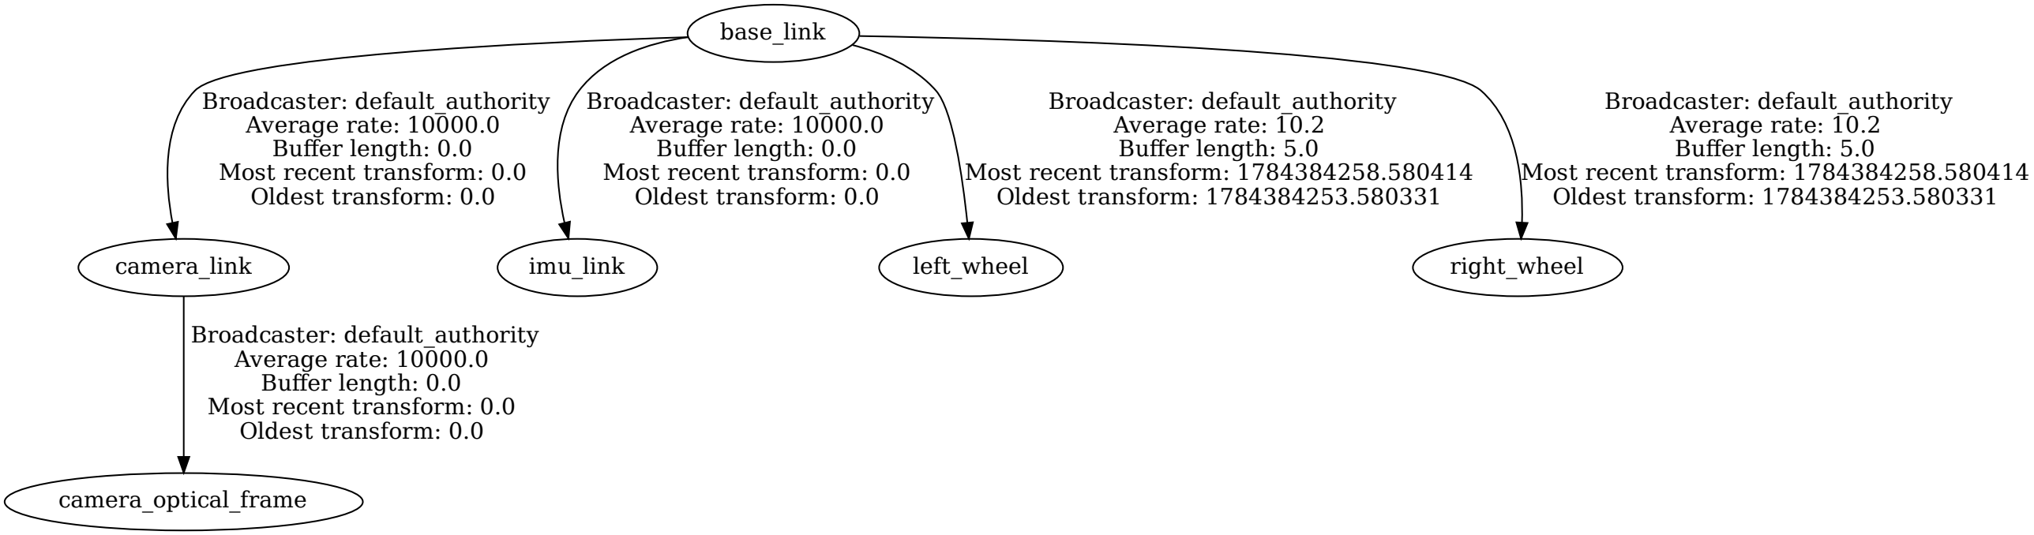
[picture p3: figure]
base_link; camera_link; Broadcaster: default_authority Average rate: 10000.0 Buffer length: 0.0 Most recent transform: 0.0 Oldest transform: 0.0; imu_link; left_wheel; Broadcaster: default_authority Average rate: 10.2 Buffer length: 5.0 Most recent transform: 1784384258.580414 Oldest transform: 1784384253.580331; right_wheel; camera_optical_frame

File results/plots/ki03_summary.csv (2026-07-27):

label | path | segment | duration_s | n_imu | pitch_mean_deg | pitch_std_deg | pitch_absmax_deg | pitch_rms_deg | zero_cross_hz | steady_mean_deg | steady_std_deg | pwm_std | pwm_sat_pct
kp=25/kd=2.0 | results/rosbag/kp25_kd20_ki03_run1 | 0 | 3.3220295906066895 | 998 | 10.797896030670655 | 4.026351971206746 | 28.840843200683587 | 5.889263153102859 | 0.0 | 4.774670255661011 | 5.020218027245091 | 73.36613340684282 | 14.343029087261785
kp=25/kd=2.0 | results/rosbag/kp25_kd20_ki03_run2 | 0 | 2.604071617126465 | 782 | 10.641968290519227 | 4.32503180674575 | 28.71163940429686 | 5.988472380251008 | 0.7680280322731506 | 5.460869905602841 | 5.403179024484038 | 80.29081564964254 | 14.980793854033292
kp=25/kd=2.0 | results/rosbag/kp25_kd20_ki03_run3 | 0 | 3.080016851425171 | 926 | 10.063840503569041 | 4.5952400225966334 | 29.144256591796875 | 5.815254938534778 | 0.6493470966155817 | 4.3461739688084045 | 5.716010514013968 | 97.48861172391692 | 14.91891891891892

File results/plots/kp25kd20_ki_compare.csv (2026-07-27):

label | path | segment | duration_s | n_imu | pitch_mean_deg | pitch_std_deg | pitch_absmax_deg | pitch_rms_deg | zero_cross_hz | steady_mean_deg | steady_std_deg | pwm_std | pwm_sat_pct
kp=25/kd=2.0/ki=0.3 | results/rosbag/kp25_kd20_ki03_run1 | 0 | 3.3220295906066895 | 998 | 10.797896030670655 | 4.026351971206746 | 28.840843200683587 | 5.889263153102859 | 0.0 | 4.774670255661011 | 5.020218027245091 | 73.36613340684282 | 14.343029087261785
kp=25/kd=2.0/ki=0.3 | results/rosbag/kp25_kd20_ki03_run2 | 0 | 2.604071617126465 | 782 | 10.641968290519227 | 4.32503180674575 | 28.71163940429686 | 5.988472380251008 | 0.7680280322731506 | 5.460869905602841 | 5.403179024484038 | 80.29081564964254 | 14.980793854033292
kp=25/kd=2.0/ki=0.0 | results/rosbag/kp25_kd20_ki0_run2 | 0 | 2.6339969635009766 | 792 | 11.339051317686986 | 4.356087576378373 | 29.817562103271484 | 6.510907511882362 | 0.0 | 5.607291984317885 | 5.533513778295575 | 85.9058489889916 | 12.76864728192162
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

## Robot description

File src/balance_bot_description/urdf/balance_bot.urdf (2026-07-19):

<?xml version="1.0"?>
<!--
  balance_bot URDF：两轮自平衡机器人的最小运动学模型
  ================================================================
  需要你用尺子量的 6 个数（单位全部是"米"，量出厘米后除以100）：

  ① BODY_LENGTH  底盘长（前后方向） —— 下面默认 0.15
  ② BODY_WIDTH   底盘宽（左右方向） —— 下面默认 0.20
  ③ BODY_HEIGHT  底盘高（泡沫板叠起来的总高）—— 下面默认 0.25
  ④ WHEEL_RADIUS 轮子半径（直径÷2，尽量量准）—— 下面默认 0.0325
  ⑤ WHEEL_WIDTH  轮子厚度 —— 下面默认 0.025
  ⑥ WHEEL_SEP/2  轮距的一半（两轮中心距÷2，尽量量准）—— 下面默认 0.11

  坐标约定（ROS 标准 REP-103）：X 朝前，Y 朝左，Z 朝上
  base_link 原点放在两轮轴心连线的中点，这样倾角就是 base_link 的 pitch
-->
<robot name="balance_bot">

  <!-- ================= 底盘 ================= -->
  <link name="base_link">
    <visual>
      <!-- 底盘几何中心相对轮轴的偏移：往上抬 半个身高 -->
      <origin xyz="0 0 0.125" rpy="0 0 0"/>
      <geometry>
        <!-- ①长 ②宽 ③高 -->
        <box size="0.15 0.20 0.25"/>
      </geometry>
      <material name="white">
        <color rgba="0.9 0.9 0.9 1.0"/>
      </material>
    </visual>
  </link>

  <!-- ================= 左轮 ================= -->
  <link name="left_wheel">
    <visual>
      <!-- 圆柱默认沿Z轴，绕X转90°让它沿Y轴（轮轴方向） -->
      <origin xyz="0 0 0" rpy="1.5708 0 0"/>
      <geometry>
        <!-- radius=④ length=⑤ -->
        <cylinder radius="0.0325" length="0.025"/>
      </geometry>
      <material name="black">
        <color rgba="0.15 0.15 0.15 1.0"/>
      </material>
    </visual>
  </link>

  <joint name="left_wheel_joint" type="continuous">
    <parent link="base_link"/>
    <child link="left_wheel"/>
    <!-- y = +轮距的一半 ⑥（左为正） -->
    <origin xyz="0 0.11 0" rpy="0 0 0"/>
    <axis xyz="0 1 0"/>
  </joint>

  <!-- ================= 右轮 ================= -->
  <link name="right_wheel">
    <visual>
      <origin xyz="0 0 0" rpy="1.5708 0 0"/>
      <geometry>
        <!-- 和左轮保持一致 -->
        <cylinder radius="0.0325" length="0.025"/>
      </geometry>
      <material name="black">
        <color rgba="0.15 0.15 0.15 1.0"/>
      </material>
    </visual>
  </link>

  <joint name="right_wheel_joint" type="continuous">
    <parent link="base_link"/>
    <child link="right_wheel"/>
    <!-- y = -轮距的一半 ⑥（右为负） -->
    <origin xyz="0 -0.11 0" rpy="0 0 0"/>
    <axis xyz="0 1 0"/>
  </joint>

  <!-- ================= IMU ================= -->
  <link name="imu_link">
    <visual>
      <origin xyz="0 0 0" rpy="0 0 0"/>
      <geometry>
        <box size="0.03 0.03 0.01"/>
      </geometry>
      <material name="blue">
        <color rgba="0.2 0.4 0.9 1.0"/>
      </material>
    </visual>
  </link>

  <joint name="imu_joint" type="fixed">
    <parent link="base_link"/>
    <child link="imu_link"/>
    <!-- IMU 相对轮轴中点的位置，大概量一下即可；默认放在底盘顶部 -->
    <origin xyz="0 0 0.20" rpy="0 0 0"/>
  </joint>

  <!-- ============ 深度相机 (Orbbec Astra) ============ -->
  <link name="camera_link">
    <visual>
      <origin xyz="0 0 0" rpy="0 0 0"/>
      <geometry>
        <!-- Astra 机身大致尺寸，不影响功能，只是视觉外观 -->
        <box size="0.04 0.165 0.03"/>
      </geometry>
      <material name="gray">
        <color rgba="0.4 0.4 0.4 1.0"/>
      </material>
    </visual>
  </link>

  <joint name="camera_joint" type="fixed">
    <parent link="base_link"/>
    <child link="camera_link"/>
    <!-- ⑦ 相机镜头中心相对轮轴中点的位置：
         x = 向前偏移量（相机在底盘前沿就是 底盘长/2 左右）
         z = 离轮轴的高度
         如果相机是俯视安装的，把 rpy 第二个数改成俯仰角（弧度，低头为正） -->
    <origin xyz="0.08 0 0.22" rpy="0 0 0"/>
  </joint>

  <!-- 相机光学坐标系：图像/点云数据用的是"Z朝前、X朝右"的光学约定，
       和 ROS 机体约定(X朝前)不同，所以固定加这个标准旋转，
       MVP2 处理点云时直接用 camera_optical_frame 即可 -->
  <link name="camera_optical_frame"/>

  <joint name="camera_optical_joint" type="fixed">
    <parent link="camera_link"/>
    <child link="camera_optical_frame"/>
    <origin xyz="0 0 0" rpy="-1.5708 0 -1.5708"/>
  </joint>

</robot>

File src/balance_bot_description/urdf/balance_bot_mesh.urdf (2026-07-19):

<?xml version="1.0" encoding="utf-8"?>
<!--
  balance_bot mesh 版 URDF —— 基于 SW2URDF 1.6.0 导出结果修正：
    1. 左右轮互换（导出时 left/right 命名反了，左轮应在 +Y）
    2. right_wheel 惯量为 0 → 复用左轮数值（轮子对称）
    3. joint 改名 *_joint，轮轴 axis 统一为 0 1 0（正转 = 前进）
    4. mesh 路径包名 balance_bot → balance_bot_description
    5. 补传感器 frame：imu_link / camera_link / camera_optical_frame

  调试用简版（纯几何体）在 balance_bot.urdf，display.launch.py 里换文件名即可切换。
-->
<robot name="balance_bot">

  <link name="base_link">
    <inertial>
      <!-- 2026-07-17 重导出更新：IMU移位后的质检属性 -->
      <origin xyz="-0.0077169 0.0055384 0.10081" rpy="0 0 0" />
      <mass value="0.84853" />
      <inertia ixx="0.0018185" ixy="2.0008E-06" ixz="3.4067E-05" iyy="0.0011604" iyz="2.6639E-05" izz="0.0014323" />
    </inertial>
    <visual>
      <origin xyz="0 0 0" rpy="0 0 0" />
      <geometry>
        <mesh filename="package://balance_bot_description/meshes/base_link.STL" />
      </geometry>
      <material name="body_white">
        <color rgba="0.92 0.92 0.94 1" />
      </material>
    </visual>
    <collision>
      <origin xyz="0 0 0" rpy="0 0 0" />
      <geometry>
        <mesh filename="package://balance_bot_description/meshes/base_link.STL" />
      </geometry>
    </collision>
  </link>

  <!-- ============ 左轮（+Y 侧） ============ -->
  <link name="left_wheel">
    <inertial>
      <origin xyz="0 0 0" rpy="0 0 0" />
      <mass value="0.019376" />
      <inertia ixx="4.194E-06" ixy="0" ixz="0" iyy="7.2222E-06" iyz="0" izz="4.194E-06" />
    </inertial>
    <visual>
      <origin xyz="0 0 0" rpy="0 0 0" />
      <geometry>
        <mesh filename="package://balance_bot_description/meshes/left_wheel.STL" />
      </geometry>
      <material name="wheel_dark">
        <color rgba="0.25 0.25 0.28 1" />
      </material>
    </visual>
    <collision>
      <origin xyz="0 0 0" rpy="0 0 0" />
      <geometry>
        <mesh filename="package://balance_bot_description/meshes/left_wheel.STL" />
      </geometry>
    </collision>
  </link>

  <joint name="left_wheel_joint" type="continuous">
    <origin xyz="0 0.0635 0" rpy="0 0 0" />
    <parent link="base_link" />
    <child link="left_wheel" />
    <axis xyz="0 1 0" />
  </joint>

  <!-- ============ 右轮（-Y 侧） ============ -->
  <link name="right_wheel">
    <inertial>
      <origin xyz="0 0 0" rpy="0 0 0" />
      <mass value="0.019376" />
      <inertia ixx="4.194E-06" ixy="0" ixz="0" iyy="7.2222E-06" iyz="0" izz="4.194E-06" />
    </inertial>
    <visual>
      <origin xyz="0 0 0" rpy="0 0 0" />
      <geometry>
        <mesh filename="package://balance_bot_description/meshes/right_wheel.STL" />
      </geometry>
      <material name="wheel_dark">
        <color rgba="0.25 0.25 0.28 1" />
      </material>
    </visual>
    <collision>
      <origin xyz="0 0 0" rpy="0 0 0" />
      <geometry>
        <mesh filename="package://balance_bot_description/meshes/right_wheel.STL" />
      </geometry>
    </collision>
  </link>

  <joint name="right_wheel_joint" type="continuous">
    <origin xyz="0 -0.0635 0" rpy="0 0 0" />
    <parent link="base_link" />
    <child link="right_wheel" />
    <axis xyz="0 1 0" />
  </joint>

  <!-- ============ IMU（frame 手写，几何已含在 base_link mesh 内） ============ -->
  <link name="imu_link" />

  <joint name="imu_joint" type="fixed">
    <parent link="base_link" />
    <child link="imu_link" />
    <!-- xyz 大致即可；rpy 必须按 HFI-A9 芯片丝印轴向填：
         板上 X 指车头且 Z 朝上 → 0 0 0；其他安装方向要改 -->
    <origin xyz="0 0 0.05" rpy="0 0 0" />
  </joint>

  <!-- ============ 深度相机 Orbbec Astra ============ -->
  <link name="camera_link" />

  <joint name="camera_joint" type="fixed">
    <parent link="base_link" />
    <child link="camera_link" />
    <!-- SW实测：坐标系1原点 → Astra红外接收镜头中心 (2026-07-17)
         y为镜头偏离车体中线的横向偏移；若镜头实际偏在车体右侧(-Y)，把y改负 -->
    <origin xyz="0.022 0.0059 0.0594" rpy="0 0 0" />
  </joint>

  <!-- 光学坐标系（Z朝前/X朝右的图像约定），rpy 固定值永不修改 -->
  <link name="camera_optical_frame" />

  <joint name="camera_optical_joint" type="fixed">
    <parent link="camera_link" />
    <child link="camera_optical_frame" />
    <origin xyz="0 0 0" rpy="-1.5708 0 -1.5708" />
  </joint>

</robot>

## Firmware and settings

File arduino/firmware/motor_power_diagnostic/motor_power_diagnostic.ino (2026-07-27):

// Direct motor-driver check. Keep both wheels elevated before uploading.
const int L_IN1 = 4, L_IN2 = 5, L_ENA = 6;
const int R_IN1 = 7, R_IN2 = 8, R_ENB = 9;
const int STBY = 10;

void setMotor(int in1, int in2, int en, int pwm) {
  digitalWrite(in1, pwm >= 0 ? HIGH : LOW);
  digitalWrite(in2, pwm >= 0 ? LOW : HIGH);
  analogWrite(en, abs(pwm));
}

void stopMotors() {
  analogWrite(L_ENA, 0);
  analogWrite(R_ENB, 0);
  digitalWrite(L_IN1, LOW); digitalWrite(L_IN2, LOW);
  digitalWrite(R_IN1, LOW); digitalWrite(R_IN2, LOW);
}

void setup() {
  pinMode(L_IN1, OUTPUT); pinMode(L_IN2, OUTPUT); pinMode(L_ENA, OUTPUT);
  pinMode(R_IN1, OUTPUT); pinMode(R_IN2, OUTPUT); pinMode(R_ENB, OUTPUT);
  pinMode(STBY, OUTPUT);
  digitalWrite(STBY, HIGH);
  stopMotors();
  Serial.begin(115200);
  delay(1000);
}

void loop() {
  Serial.println("MOTOR_PULSE");
  setMotor(L_IN1, L_IN2, L_ENA, 150);
  setMotor(R_IN1, R_IN2, R_ENB, 150);
  delay(500);
  stopMotors();
  Serial.println("MOTOR_STOP");
  delay(3000);
}

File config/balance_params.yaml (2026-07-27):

# Tuned 2026-07-25.  Sustains balance indefinitely: 228.7 s in one segment with
# pitch error inside +/- 1 deg.  See docs/05_balance_achieved_2026-07-25.md for
# how each value was derived and for the ones that must not be re-swept.
balance_controller:
  ros__parameters:
    # Mechanical balance point.  Derived from the mean pitch of long engaged
    # segments, not by trial and error.  Do not refine below ~0.2 deg; that is
    # run-to-run noise.  Judge it by the velocity integral mean instead, which
    # should sit near zero and never clamp.
    pitch_offset_deg: 7.53
    capture_offset_on_engage: false

    # Angle inner loop.  kp/ki inherited from the original tuning.
    kp: 70.0
    ki: 0.0
    # 5.0 -> 3.5 to stop the loop self-exciting while driving.  Filtering alone
    # only moved the ring (see pitch_rate_filter_alpha below); killing it needs
    # less loop gain at that frequency.  Measured back to back in one session:
    # the forward command's body motion went from a 7.00 Hz ring with the output
    # swinging 356 PWM peak to peak, to 0.44 Hz (the ordinary slow surge) at 127
    # peak to peak.  Station keeping was unaffected -- errRMS 0.34-0.38 deg
    # against 0.35 at kd 5.0, i.e. inside run-to-run noise -- so the damping
    # given up was only ever feeding the oscillation.
    kd: 3.5
    # 0.3 put the one-pole cutoff at 0.3*145/(2*pi) = 6.9 Hz.  Driving (unlike
    # station keeping) breaks the wheels loose repeatedly, and that broadband
    # kick rang the loop at 9.18 Hz with the output swinging 397 PWM peak to
    # peak -- the judder visible when the robot moves.  Dropping to 0.15 moves
    # the cutoff to 3.5 Hz: forward judder disappeared from the body motion
    # (err went 9.18 Hz -> 0.46 Hz) and reverse err RMS fell 0.63 -> 0.45.
    #
    # The oscillation FREQUENCY moved with this filter (9.18 -> 7.07 Hz), which
    # proves it is loop self-excitation, not a mechanical resonance -- a
    # structural resonance cannot be shifted by a software coefficient.  So the
    # remaining 7 Hz ring needs less loop gain there (lower kd), or better, the
    # gyro's raw angular_velocity.y instead of a differentiated pitch, which
    # would remove the differentiation noise that forces heavy filtering in the
    # first place.  Not yet done -- see docs/07 section 11.
    pitch_rate_filter_alpha: 0.15

    # Outer loop.  Integrating wheel speed gives position, so ki_v is the
    # position term and kp_v is its damping.  Both must be NEGATIVE: to slow a
    # forward roll the wheels must first drive forward harder so the base moves
    # ahead of the centre of mass and the body pitches back.
    kp_v: -0.008
    ki_v: -0.005
    max_offset_trim_deg: 4.0
    max_velocity_integral: 500.0
    # Must be far slower than the angle loop.  At the 100 Hz encoder rate the
    # old 0.3 put the outer loop cutoff near 4.8 Hz, faster than the inner loop.
    velocity_filter_alpha: 0.06

    # Direct wheel-speed braking is the wrong tool: it makes the body pitch
    # further over and the angle loop immediately fights it.  Keep at 0.
    kd_wheel: 0.0
    max_wheel_damping_pwm: 0.0

    # Yaw.  turn_velocity = left_v - right_v, and the bridge maps
    # left = u - sync, right = u + sync, so this gain is positive.
    wheel_sync_kp: 0.4
    # Pure P could not turn the robot right: the correction sat at -34 PWM mean
    # (-59 peak) for the whole command while the measured loaded breakaway is
    # 65-80, so the wheels never broke free differentially and right turns
    # reached only 28% of setpoint.  Left turns were fine because the machine
    # already drifts left and needed just +8.  The cap was the binding
    # constraint, not the gain, so it goes above breakaway; the leaky integral
    # then climbs until the wheels release and decays once the error is gone,
    # so it does not lock the heading the way a pure integrator would.
    # Effective low-frequency gain = kp + ki*tau = 0.4 + 0.08*6 = 0.88.
    wheel_sync_ki: 0.08
    turn_integral_leak_s: 6.0
    max_turn_integral: 2000.0
    max_wheel_sync_pwm: 110.0
    turn_velocity_filter_alpha: 0.15

    # IMU zero-bias drifts with time powered: 0.86 deg over two hours on
    # 2026-07-26, and an overnight cool-down put it back to +0.002 deg of the
    # configured value.  While station keeping with zero mean wheel speed, the
    # trim the velocity loop holds on average IS the offset error, so absorb it.
    # tau must stay far above the position loop (~3-6 s) or the two integrators
    # fight; 120 s is ~20x slower and still 30x faster than the drift itself.
    # 0 disables.  capture_offset_on_engage stays false: it would capture
    # whatever angle the robot happens to be held at, not the balance point.
    offset_adapt_tau_s: 120.0
    max_offset_bias_deg: 2.0
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

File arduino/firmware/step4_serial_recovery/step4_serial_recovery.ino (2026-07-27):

// Recovery firmware: motor serial protocol plus watchdog, with encoder ISRs
// intentionally disabled while diagnosing an interrupt flood.
const int L_IN1 = 4, L_IN2 = 5, L_ENA = 6;
const int R_IN1 = 7, R_IN2 = 8, R_ENB = 9;
const int STBY = 10;

const unsigned long SEND_PERIOD_MS = 20;
const unsigned long CMD_TIMEOUT_MS = 250;

String cmdBuf = "";
unsigned long lastSend = 0;
unsigned long lastCmd = 0;

void setMotor(int in1, int in2, int en, int pwm) {
  if (pwm > 0) {
    digitalWrite(in1, HIGH); digitalWrite(in2, LOW);
  } else if (pwm < 0) {
    digitalWrite(in1, LOW); digitalWrite(in2, HIGH);
    pwm = -pwm;
  } else {
    digitalWrite(in1, LOW); digitalWrite(in2, LOW);
  }
  analogWrite(en, constrain(pwm, 0, 255));
}

void stopMotors() {
  setMotor(L_IN1, L_IN2, L_ENA, 0);
  setMotor(R_IN1, R_IN2, R_ENB, 0);
}

void setup() {
  pinMode(L_IN1, OUTPUT); pinMode(L_IN2, OUTPUT); pinMode(L_ENA, OUTPUT);
  pinMode(R_IN1, OUTPUT); pinMode(R_IN2, OUTPUT); pinMode(R_ENB, OUTPUT);
  pinMode(STBY, OUTPUT);
  digitalWrite(STBY, HIGH);
  stopMotors();
  Serial.begin(115200);
  cmdBuf.reserve(24);
  lastCmd = millis();
}

void loop() {
  if (millis() - lastSend >= SEND_PERIOD_MS) {
    Serial.println("E,0,0");
    lastSend = millis();
  }

  while (Serial.available()) {
    char c = Serial.read();
    if (c == '\n') {
      if (cmdBuf.startsWith("M,")) {
        int comma = cmdBuf.indexOf(',', 2);
        if (comma > 2) {
          int leftPwm = cmdBuf.substring(2, comma).toInt();
          int rightPwm = cmdBuf.substring(comma + 1).toInt();
          setMotor(L_IN1, L_IN2, L_ENA, leftPwm);
          setMotor(R_IN1, R_IN2, R_ENB, rightPwm);
          lastCmd = millis();
        }
      }
      cmdBuf = "";
    } else {
      cmdBuf += c;
    }
  }

  if (millis() - lastCmd > CMD_TIMEOUT_MS) {
    stopMotors();
  }
}

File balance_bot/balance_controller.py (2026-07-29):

import math

import rclpy
from rclpy.node import Node
from sensor_msgs.msg import Imu
from std_msgs.msg import String, Float32MultiArray, MultiArrayDimension
from geometry_msgs.msg import Twist

# Field order of /balance/state.  Recorded into the message layout label so a
# bag stays readable without this source file.
STATE_FIELDS = (
    'pitch', 'err', 'rate', 'trim', 'offset', 'vel', 'vel_raw', 'turn',
    'v_ref', 'turn_ref', 'vel_int', 'u', 'sync', 'engaged',
    'bias', 'turn_int',
)


class BalanceController(Node):
    """平衡控制器v2：角度内环(IMU pitch→PID) + 速度外环(编码器轮速→目标倾角修正)。

    符号约定（2026-07-19全链路实测定稿）：
      前倾 = pitch正 = 需要正向(前进)PWM去追重心
    内环在IMU回调里跑(~284Hz)；外环在编码器回调里算轮速，
    修正量叠加到pitch_offset_deg上，压制角度环兜不住的净漂移。
    参数可用 ros2 param set 在线调。

    话题分层（2026-07-26遥控接入时确立）：
      /cmd_vel     人的速度意图，SI单位(m/s, rad/s)，由teleop发布
      /motor_cmd   本节点输出给serial_bridge的PWM指令(PWM/100)
    遥控不新增回路：只是把速度环和偏航环的设定值从0换成指令值。
    """

    def __init__(self):
        super().__init__('balance_controller')
        self.declare_parameter('kp', 20.0)     # PWM每度
        self.declare_parameter('ki', 0.0)      # 最后再加
        self.declare_parameter('kd', 0.6)      # PWM每(度/秒)
        self.declare_parameter('pitch_offset_deg', 0.0)  # 机械平衡点不在0度时补偿
        self.declare_parameter('capture_offset_on_engage', False)
        self.declare_parameter('capture_offset_bias_deg', 0.0)  # Bias after capturing the upright pose
        self.declare_parameter('capture_settle_time_sec', 0.8)
        self.declare_parameter('capture_rate_below_dps', 3.0)
        self.declare_parameter('max_tilt_deg', 30.0)     # 超过判定摔倒，切断输出
        self.declare_parameter('max_pwm', 255.0)         # 输出上限；手扶调参时用较小值限制冲击
        self.declare_parameter('max_pwm_fwd', 0.0)       # >0 overrides the positive-output limit
        self.declare_parameter('max_pwm_bwd', 0.0)       # >0 overrides the negative-output limit
        self.declare_parameter('max_wheel_velocity', 0.0)  # <=0 disables wheel-runaway latching
        self.declare_parameter('motor_output_sign', 1.0)  # Set to -1.0 when physical wheel polarity is reversed
        self.declare_parameter('latch_on_fall', True)    # 保护触发后保持断开，避免自动再次接管
        self.declare_parameter('engage_below_deg', 3.0)  # 扶正到该角度内才上电
        self.declare_parameter('engage_rate_below_dps', 15.0)  # 角速度也需低于该值才接管，避免正摆动中途接管扛不住动量
        self.declare_parameter('deadband_pwm_fwd', 0.0)  # 正向(前进)死区前馈，两方向静摩擦不对称需分开设
        self.declare_parameter('deadband_pwm_bwd', 0.0)  # 反向(后退)死区前馈
        self.declare_parameter('deadband_err_deg', 1.0)  # 误差小于该角度不启动死区前馈，避免过零颤振
        self.declare_parameter('deadband_rate_dps', 0.0)  # Allow friction compensation for fast D-term braking
        self.declare_parameter('deadband_ramp_deg', 0.0)  # >0 enables smooth static-friction compensation
        self.declare_parameter('deadband_output_ramp_pwm', 0.0)  # >0 ramps static-friction assist from PID effort
        self.declare_parameter('deadband_dither_hz', 0.0)  # >0 enables sigma-delta low-effort static-friction pulses
        self.declare_parameter('deadband_dither_pulse_ms', 0.0)  # Minimum pulse width; 0 keeps one-control-frame pulses
        self.declare_parameter('deadband_velocity_threshold', 0.0)  # Compensation fades out above this wheel speed
        self.declare_parameter('recovery_pwm', 0.0)  # Extra authority after the tilt escapes the center band
        self.declare_parameter('recovery_pwm_fwd', -1.0)  # Negative uses recovery_pwm as a fallback
        self.declare_parameter('recovery_pwm_bwd', -1.0)  # Negative uses recovery_pwm as a fallback
        self.declare_parameter('recovery_err_deg', 0.7)
        self.declare_parameter('recovery_ramp_deg', 0.4)
        self.declare_parameter('kp_v', 0.0)      # 速度环比例：ticks/s → 目标倾角修正(度)
        self.declare_parameter('ki_v', 0.0)      # 速度环积分：消除长期位置漂移
        self.declare_parameter('kd_wheel', 0.0)  # Direct wheel-speed damping, PWM per (tick/s)
        self.declare_parameter('max_wheel_damping_pwm', 0.0)  # <=0 leaves direct damping uncapped
        self.declare_parameter('max_wheel_damping_return_pwm', 0.0)  # Higher cap while body is returning upright
        self.declare_parameter('wheel_sync_kp', 0.0)  # PWM per left/right wheel-speed difference
        # 纯P产生的差模修正可能整段都低于静摩擦突破电压，轮子挣不脱。
        # 泄放积分会一直爬到挣脱为止，误差消失后自行衰减。
        self.declare_parameter('wheel_sync_ki', 0.0)
        self.declare_parameter('turn_integral_leak_s', 6.0)
        self.declare_parameter('max_turn_integral', 2000.0)
        self.declare_parameter('max_wheel_sync_pwm', 0.0)  # <=0 leaves wheel synchronization uncapped
        self.declare_parameter('turn_velocity_filter_alpha', 0.15)
        # IMU零偏随通电时间漂移(实测两小时0.86度，冷却后完全归零)。
        # 站桩时速度环平均要顶住的trim，本身就等于零点误差，慢慢把它吸收掉。
        # 时间常数必须远大于位置环，否则两个积分器会互相打架。0=关闭。
        self.declare_parameter('offset_adapt_tau_s', 0.0)
        self.declare_parameter('max_offset_bias_deg', 2.0)
        self.declare_parameter('max_offset_trim_deg', 5.0)  # 速度环能修正offset的最大幅度，防止跑飞
        self.declare_parameter('max_velocity_integral', 500.0)  # 位置项抗饱和限幅(ticks)
        self.declare_parameter('velocity_filter_alpha', 0.3)  # 速度信号低通滤波系数(0~1)，越小越平滑但越滞后

        # ---- 遥控 ----
        # 输入是SI单位的速度意图，输出是给serial_bridge的PWM。两者必须分开，
        # 否则teleop和本节点会抢同一个/cmd_vel互相覆盖。
        self.declare_parameter('cmd_vel_topic', '/cmd_vel')
        self.declare_parameter('motor_cmd_topic', '/motor_cmd')
        # m/s ↔ ticks/s 换算。与serial_bridge的ticks_per_rev和URDF轮径保持一致，
        # 改了机械参数这里也要跟着改。
        self.declare_parameter('ticks_per_rev', 277.5)
        self.declare_parameter('wheel_radius_m', 0.0325)
        self.declare_parameter('wheel_separation_m', 0.22)
        # 永远不要相信输入源：teleop_twist_keyboard默认0.5m/s，直接超过整车安全限。
        self.declare_parameter('max_cmd_linear_mps', 0.25)
        self.declare_parameter('max_cmd_angular_rps', 1.2)
        # 断连/停发即回零，指令超时是遥控失效保护的唯一可靠位置。
        self.declare_parameter('cmd_timeout_s', 0.5)
        # 阶跃指令会把车掀翻：设定值必须斜坡上升，让角度环有时间把重心送出去。
        self.declare_parameter('cmd_accel_ticks_s2', 250.0)
        self.declare_parameter('cmd_yaw_accel_ticks_s2', 600.0)
        # ki_v积分的是位置误差。行驶中继续累积会导致松手后倒车"补距离"，
        # 故有指令时改为泄放；回到零指令后恢复累积，站桩性能不受影响。
        self.declare_parameter('drive_integral_leak_s', 0.5)
        self.declare_parameter('drive_deadzone_ticks', 20.0)
        # 行驶结束回到站桩的瞬间清零位置积分：积分量代表相对"上一个保持点"的
        # 位移，而操作者刚刚是有意离开那个点的。不清零车会一路爬回出发地
        # （T8实测全程净位移+0.01圈——它精确回到了原点，这不是遥控想要的）。
        self.declare_parameter('reset_integral_on_stop', True)
        # 失速解锁。行驶时泄放积分会让trim停在够不到静摩擦突破电压的地方：
        # 实测车前倾到trim +0.84度后车身照做、角度环误差只剩0.15度、输出塌缩到
        # 14 PWM，而负载突破电压是65~80，于是车前倾着站在原地形成稳定死锁，
        # 指令还在发也走不动。轮速低于该阈值且有速度指令时冻结泄放，
        # 让积分继续累积把trim顶上去直到轮子挣脱。<=0 关闭。
        self.declare_parameter('stall_velocity_ticks', 30.0)
        self.declare_parameter('angular_cmd_sign', 1.0)  # 实测方向不对时置-1
        self.declare_parameter('state_publish_decim', 3)  # /balance/state降频倍数
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

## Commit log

2026-03-25 docs: add Week1 HFI-A9 IMU troubleshooting notes
2026-03-25 feat: add hfi_imu_node and imu_reader, Week1 complete
2026-04-01 feat: Week2 complete — dual motor firmware and serial protocol verified
2026-04-02 Stage 3: add serial_bridge node, bringup launch file
2026-04-02 docs: add stage 1-3 notes and troubleshooting records
2026-07-19 Week4 + MVP0: URDF/RViz integration, encoder-driven joint states, harness mapping fixes
    - SW2URDF mesh export ported to ROS2 (left/right swap, inertia, sensor frames fixed)
    - serial_bridge: by-id stable serial path, /joint_states from encoders (20Hz),
    left/right harness mapping normalized for both encoders and motor commands
    - hfi_imu_node registered as entry point and wired into bringup (was never launched)
    - imu_reader: pitch formula corrected (was computing roll)
    - MVP0 artifacts: teleop+RViz demo video, RViz screenshots, TF tree PDF
    [balance_bot.urdf, balance_bot_mesh.urdf, base_link.STL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]
2026-07-25 Close the balance loops: four-stage cascade, 228 s of sustained balance
    Add the velocity, position and yaw loops around the existing angle loop, and
    freeze the tuned result into a reproducible configuration.
    Key corrections:
    - kp_v flipped from positive to negative. A balancing robot is non-minimum
    phase: to slow down it must first accelerate, so the outer gain must be
    negative. The previous positive value was positive feedback and is why the
    velocity loop never worked. ki_v is negative for the same reason.
    - kd_wheel set to 0. Damping wheel speed directly is a naive brake; it pitches
    the body further over and fights the angle loop head on.
    - velocity_filter_alpha 0.3 -> 0.06. At th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
    [ki03_summary.csv, kp25kd20_ki_compare.csv, tuning_report.csv]
2026-07-27 Drive the robot while it balances, and record the evidence
    /cmd_vel was serving two different meanings at once: human velocity intent for
    the MVP0 keyboard teleop, and the PWM setpoint the balance controller sends to
    serial_bridge. Whichever ran second overwrote the other, so driving under
    balance was impossible. Split them: /cmd_vel stays the SI-unit intent and
    /motor_cmd carries PWM. bringup.launch.py keeps /cmd_vel as its default so the
    MVP0 workflow is untouched; balance.launch.py overrides it.
    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
2026-07-27 Kill the driving judder, and find why forward sometimes stops dead
    Lowering kd from 5.0 to 3.5 removes the oscillation that showed up whenever the
    robot drove. Measured back to back in one session, changing the gain live so the
    floor position and temperature were identical: the forward command's body motion
    went from a 7.00 Hz ring with the output swinging 356 PWM peak to peak, down to
    0.44 Hz, which is just the ordinary slow surge, at 127 peak to peak. Station
    keeping was unaffected -- errRMS 0.34-0.38 deg against 0.35 at the old gain, so
    inside run-to-run noise. The damping given up was only ever feeding the
    oscillation.
    Retract the standing advice to feed the D term from the gyro instead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
    [balance_params.yaml]
2026-07-27 Try to unstick the drive stall via the integral, and record why it fails
    Driving forward can lock up: the velocity loop raises the target tilt, the body
    actually reaches it, so the angle error collapses to 0.15 deg and the output
    with it, to about 14 PWM against a 65-80 measured breakaway. The wheels never
    move again and the robot stands there leaning, still being commanded.
    The attempt here lets the integral keep accumulating while stalled instead of
    leaking, so the trim climbs until the wheels break free. It does break free.
    It also overshoots to 3.2x setpoint -- +343 against +108.7 -- because the
    integral is still at -290 when motion resumes and only unwinds with a 6 s leak.
    What follows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
    [balance_controller.py, balance_params.yaml]
2026-07-28 Wire up the gamepad, and fix the stick sign that was backwards
    The 2.4G pad enumerates as an Xbox 360 controller over XInput, so the in-kernel
    xpad driver claims it and /dev/input/js0 appears with no driver work at all.
    game_controller_node reports it as a standard SDL layout, which is what
    config/teleop_joy.yaml was written against.
    Three of the four mappings in that config were already right. The fourth was
    not, and it was the one that mattered: scale_linear was negative, written on the
    assumption that SDL's stick-up-is-negative convention reaches the topic. It does
    not -- game_controller_node already flips it, and the left stick pushed forward
    reads axis 1 = +1.0. Left as written, pushin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
2026-07-28 MVP2 groundwork: get depth out of a discontinued camera, and prove it is free
    Two questions had to be answered before any obstacle-avoidance code was worth
    writing: can the Astra Pro produce depth at all, and does streaming it cost the
    balance loop anything. Both are falsifiable in an afternoon and either one
    failing would have invalidated the plan behind it. Nothing else was built yet.
    Driver. The Astra Pro is a 2016-era discontinued device and splits in two: the
    RGB half is plain UVC and the kernel claims it, while the depth half is a
    vendor-specific interface with no kernel driver, reachable only through libusb.
    Two supported-looking routes failed first. ros-jazzy-orbbec-camera, the curr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
2026-07-28 Clear the last two MVP2 risks: braking distance and a gravity-aligned frame
    Braking distance needed no new experiment. Every teleop command in the last few
    days is followed by a release, which is a braking event, so integrating wheel
    speed from the moment the setpoint returns to zero measures it directly from
    bags recorded days ago for other reasons. Worst case 0.10 m at 0.174 m/s, with
    stop time steady near 0.9 s and distance roughly linear in speed, so the 0.25
    m/s clamp extrapolates to about 0.15 m.
    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
2026-07-28 docs: record tooling decisions and the Gazebo prerequisite
    Writes down which parts of the ROS2 ecosystem this project should adopt and,
    more usefully, which it should not. MoveIt plans motion for kinematic chains
    and there is no arm here. ros2_control would make serial_bridge more orthodox
    without solving any problem it currently has.
    Gazebo is worth it for the avoidance state machine -- crashing into simulated
    walls costs nothing, while every real crash costs a person walking over to
    stand the robot back up. It is not worth it for the inner loop, and the reason
    is specific: every hard problem of the last week was friction breakaway,
    stick-slip, IMU bias drift and a scheduler stall, none of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
2026-07-28 Pair every depth frame with the attitude it was taken at
    Depth on this robot is not geometry until you know how the body was tilted when
    the frame arrived, and the first attempt at reading the geometry proved it the
    hard way. Projecting a frame under a level assumption put 27334 points -- a
    quarter of the valid ones -- below the floor, which is physically impossible.
    The body was lying at -82 deg at the time, because the balance controller was
    not running and nothing in the pipeline said so.
    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
2026-07-28 Fix the depth projection, and stop the camera stamping from its own clock
    Two bugs, both of which had been quietly producing plausible-looking output.
    The projection into the gravity-aligned frame expanded a quaternion
    multiplication by hand against a yaw-only operand and put the sine term on the
    wrong component of y. It survived its first test because that frame was
    captured at -82 deg, with the camera facing the ceiling, so every point landed
    in the same height bucket and a wrong rotation was indistinguishable from a
    right one. Upright, the same code put 100% of valid points below the floor.
    Rewritten with helper functions rather than inlined algebra: upright now reads
    9% floor, 11% low o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
2026-07-28 Add an obstacle scan, and stop it reporting ignorance as safety
    Publishes a LaserScan on /obstacle/scan and a scalar on /obstacle/nearest,
    built from depth projected into the gravity-aligned frame. A scan of 64 ranges
    travels anywhere; the 640x480 float32 depth it comes from is about 29 MB/s and
    this project has already measured that as enough to saturate the link DDS runs
    over. Heights are measured against gravity rather than the chassis, because at
    1 m the four degrees the outer loop tilts the body is 7 cm of apparent height,
    which is the whole difference between floor and obstacle.
    Two bugs, both found by looking at output that was superficially reasonable.
    The scalar summary conflated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
    [obstacle_scan.py]
2026-07-28 Verify the obstacle scan against a real obstacle
    Held upright, the scan sits at 1.98 m with 0.01 m of scatter across dozens of
    frames, drops to 0.53-0.71 m when something is placed in front, and returns to
    1.98 m the moment it is removed. Repeated four times. Response is immediate,
    with no lag or residue.
    The measurement also puts a number on a limitation that mattered more than the
    detection: around 28 of 64 bearings sit permanently unknown, and only 3-4 ever
    read clear. Nearly half the field of view carries no data, which follows from
    the camera being 9.2 cm off the ground and seeing most surfaces at a grazing
    angle. An avoidance rule of 'unknown means impassable' would leave this robot
    u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
2026-07-28 Add the obstacle guard, and verify it on the bench
    The guard sits between command sources and the balance controller: /cmd_vel_raw
    in, /cmd_vel out. It only ever reduces the forward component, so the operator
    stays in the loop and an autonomous command source can be added later without
    touching it. Reverse and rotation always pass -- a guard that can stop the robot
    but not let it back out of a corner strands it.
    Stopping distance is set by the sensor rather than the brakes. Braking from the
    fastest speed measured 0.10 m, but the Astra sees nothing closer than about
    0.6 m, so an obstacle being approached disappears from the scan exactly when it
    matters most. Stopping at 0.7 m keeps the decis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
    [avoidance_guard.py]
2026-07-29 Add autonomous wandering, and rewrite the README around the reasoning
    Under manual control an obstacle guard that only stops is close to pointless:
    the operator can see the obstacle and stop sooner. The guard earns its place by
    sitting under a command source that cannot see, which is what explorer is. It
    drives, turns toward whichever side the scan says is more open, and backs up
    when a full sweep finds no way out.
    Turn direction comes from the scan rather than being fixed. Always turning the
    same way walks a robot into a corner and holds it there, because the corner is
    symmetric and the rule is not; comparing clearance either side breaks that
    symmetry with evidence.
    It publishes /cmd_vel_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
    [explorer.py]
2026-07-29 Close the loop: the robot balances, sees, and drives itself around obstacles
    Full stack running together for the first time. 486.9 s of unbroken balance with
    errRMS 0.69 deg while the explorer drove, turned and reversed on its own, with
    four interruptions across a 1174 s session -- all of them the robot being picked
    up or set down, not control failures.
    The three states all appeared on real hardware:
    DRIVE near 2.36 -> +0.10 m/s
    TURN near 1.07 -> 0.00 m/s, +0.60 rad/s triggered at 1.1 m as designed
    BACKUP near 0.87 -> -0.08 m/s a full sweep found no way out
    TURN -0.60 rad/s direction flipped after backing
    The layering did wha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
2026-07-29 Stop treating the path as a wedge, and steer for gaps instead of stopping
    The robot halted while still far from anything, and the cause was geometry
    rather than timid parameters. The corridor used to decide "is something in the
    way" was a fixed half-angle, but the robot is a fixed width. A wedge flares:
    +-0.30 rad spans 0.62 m at 1 m and 1.86 m at 3 m against a 0.22 m track, so an
    object 0.6 m off to one side at 2 m counted as blocking a path it came nowhere
    near. Both the guard and the explorer now test lateral offset in metres,
    r*sin(theta), against the strip the robot actually occupies.
    The effect is visible in a single line of the run: at near=1.87 the guard
    reports CLEAR 1.86. Those tw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
    [avoidance_guard.py, explorer.py]
2026-07-29 Fix the three faults that drove the robot into a table leg
    It hit a table leg, and the logs show the scan saw that leg the whole way in --
    0.86 to 0.88 m, steady, for three seconds. Not a blind spot and not a missed
    detection. Three separate faults compounded.
    The explorer and the guard had overlapping bands with a dead zone between them.
    The guard begins tapering at 1.20 m and by 0.87 m had cut speed to 0.045 m/s,
    while the explorer's turn trigger sat at 0.85 m and never fired. Between those
    two numbers the robot crawled straight ahead with gap=none the entire time,
    turning for neither reason. Absence of a passable gap is now itself grounds to
    turn, independent of distance: not being able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
    [avoidance_guard.py, explorer.py]
2026-07-29 Sweep and commit instead of sweeping and hoping, and widen the corridor
    Cornered, the robot used to sweep about 206 degrees, back up 12 cm, and sweep
    again, indefinitely. The reason is that TURN only ended when some direction
    exceeded a clearance threshold, and in a tight space no direction does. Waiting
    for something good enough does not terminate when nothing is good enough.
    It now measures the sweep against IMU heading rather than a timer, remembers
    which heading was most open along the way, and once a full arc is covered turns
    to that heading and drives. Picking the best of what was actually seen always
    terminates. Backing up is kept as the fallback for when even that fails, since
    the r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
    [avoidance_guard.py, explorer.py]
2026-07-29 Boot into autonomy, hand over to a gamepad on demand, and survive a dead sensor
    Three pieces that turn a set of nodes into something that can be switched on.
    cmd_mux owns /cmd_vel_raw and picks between the explorer and teleop. Detection
    is by traffic rather than by asking whether a gamepad exists: teleop_twist_joy
    publishes only while its deadman is held, so a manual message arriving already
    means a hand is on the controls. Taking over is immediate, handing back waits
    half a second -- the asymmetry is deliberate, since a human grabbing the sticks
    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
2026-07-29 docs: record how autonomy was made useful, and what broke on the way
    Covers the second half of MVP2: why a guard that only stops is close to
    pointless under manual control, the wedge-shaped corridor that made the robot
    halt while still far from anything, follow-the-gap steering, the three
    compounding faults behind a collision with a table leg it could see the whole
    time, why sweeping until something clears a threshold never terminates in a
    tight space, mode arbitration, the systemd boot path, and the frozen-sensor
    failure that only a reboot could expose.
    The through-line is that almost none of these were parameter problems. They
    were geometry, overlapping module boundaries, a waiting condit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
